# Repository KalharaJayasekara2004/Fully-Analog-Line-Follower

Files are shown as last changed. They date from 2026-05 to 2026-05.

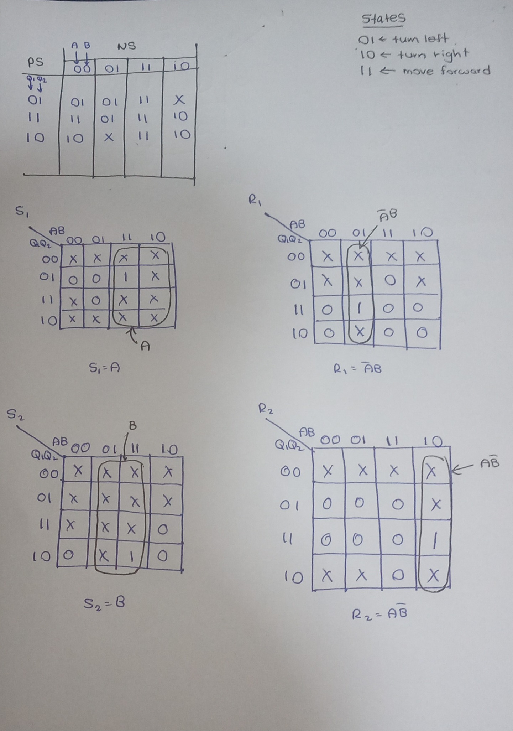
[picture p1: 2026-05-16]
Fully Analog Line Follower/Images/Logic.jpeg

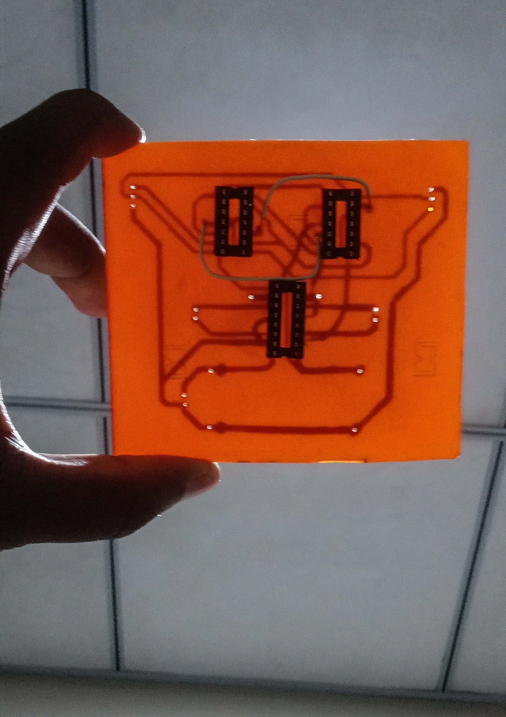
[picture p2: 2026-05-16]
Fully Analog Line Follower/Images/pcb.jpg

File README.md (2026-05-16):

# Fully Analog Line Following Robot

## 📌 Overview

This project presents the design and implementation of a fully analog line following robot developed for the EE2030 module at the University of Peradeniya.

The robot operates entirely without microcontrollers and is based on analog circuitry, logic gates, and flip-flop based control logic.

---

## ⚙️ Features

- Fully analog implementation
- No microcontroller usage
- SR flip-flop based control logic
- NAND gate logic optimization
- PCB-based hardware design
- Dash-line handling capability

---

## 🔧 Components Used

- KY-033 sensors
- L293D motor driver
- SR flip-flops
- NAND gates
- N20 DC motors
- Li-ion batteries

---

## 🖼️ Project Images

### Final Robot
Final Robot

---

## 🎥 Demonstration Video

[Click here to watch the final demonstration](https://drive.google.com/file/d/1bMnqlzevseig7BFVXOJsCPHhtffpjha0/view?usp=sharing)

---

## 📄 Documentation

The complete project report is available in the `report` folder.

---

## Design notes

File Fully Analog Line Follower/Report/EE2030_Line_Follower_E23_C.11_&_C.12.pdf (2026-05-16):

1

EE2030

# SEMESTER 3 - Group Project

## Group Members

E/23/135
E/23/138
E/23/145
E/23/150
E/23/151
E/23/158

# Week 01

## Week 1 – Initial Study and Logic Design

In Week 1, we first analyzed the basic operating logic of a line-following robot using two sensors. Based on the possible sensor output combinations, we constructed K-maps to simplify the control logic and determine the required motor control signals. This helped us to clearly understand how the robot should respond to different line positions. After gaining a rough understanding of the system behavior using two sensors, we extended the same approach to a three-sensor configuration in order to improve line detection accuracy and control reliability. The corresponding K-maps and logic diagrams were drawn and are included below.

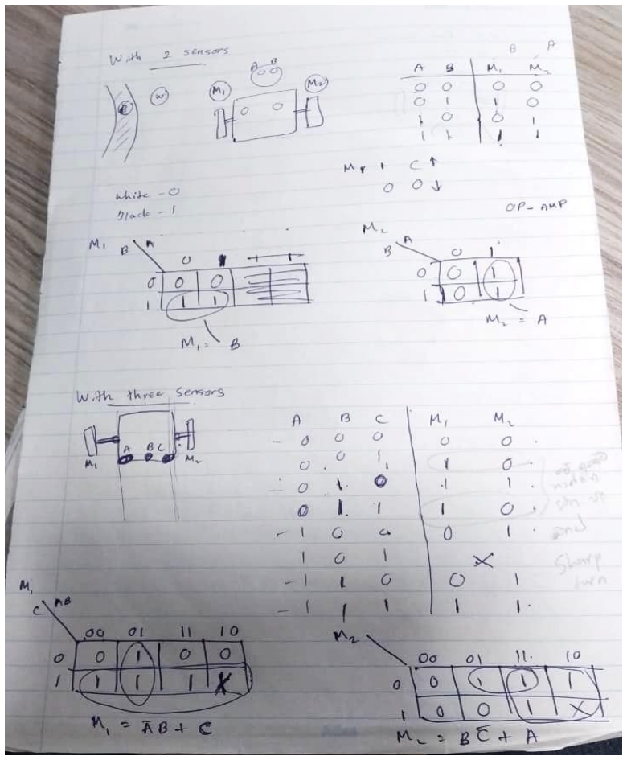
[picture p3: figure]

Figure 1: Karnaugh map representation for sensor-based motor control logic

# Week 02

## Week 2 – Sensor Signal Conditioning and Testing

In Week 2, we discussed methods to convert the analog output of the line sensors into digital signals suitable for control logic implementation. For this purpose, we decided to use operational amplifiers with adjustable potentiometers as comparators to set appropriate threshold levels. A rough circuit diagram was designed for the TCRT5000 sensor interfaced with an op-amp, and different sensor array configurations were evaluated to improve line detection accuracy. Through this analysis, we identified that a circular or V-shaped sensor array provides better line tracking performance compared to a straight-line configuration. Following the discussion session, the designed circuit was physically implemented and tested, using LED indicators to verify high and low output states of the comparator. The related circuit diagrams, implemented hardware, and sensor array configurations are shown below.

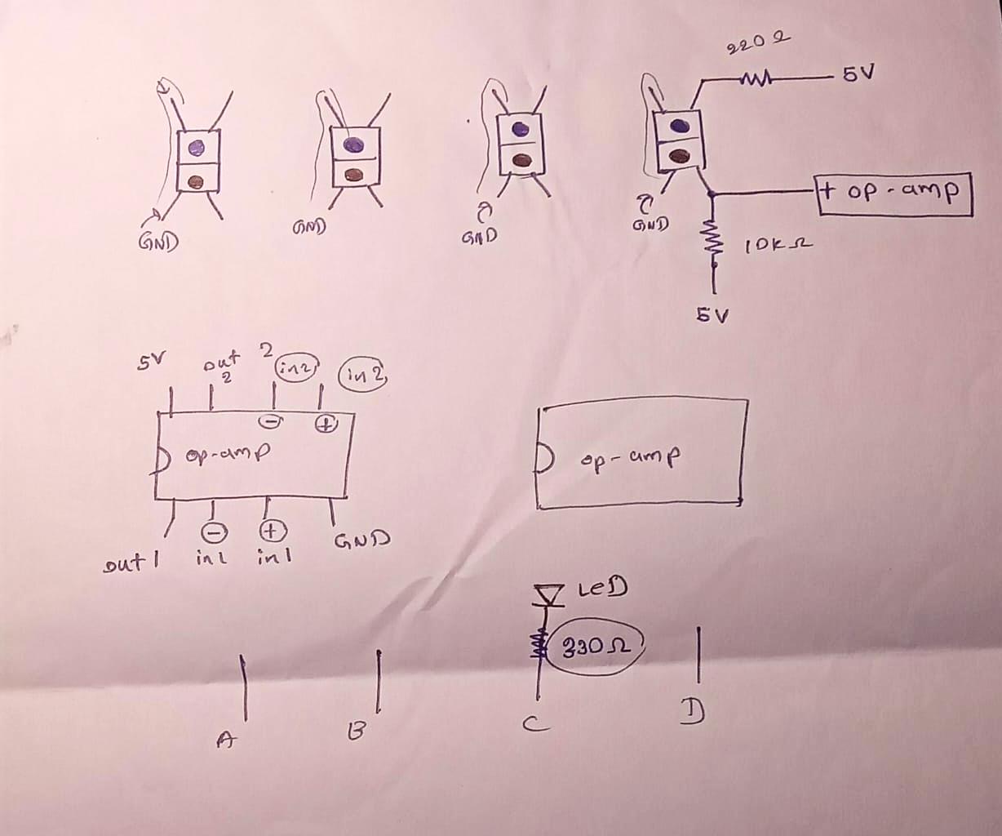
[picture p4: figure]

Figure 2.1: Rough circuit diagram of TCRT5000 sensor with op-amp comparator(LM358)

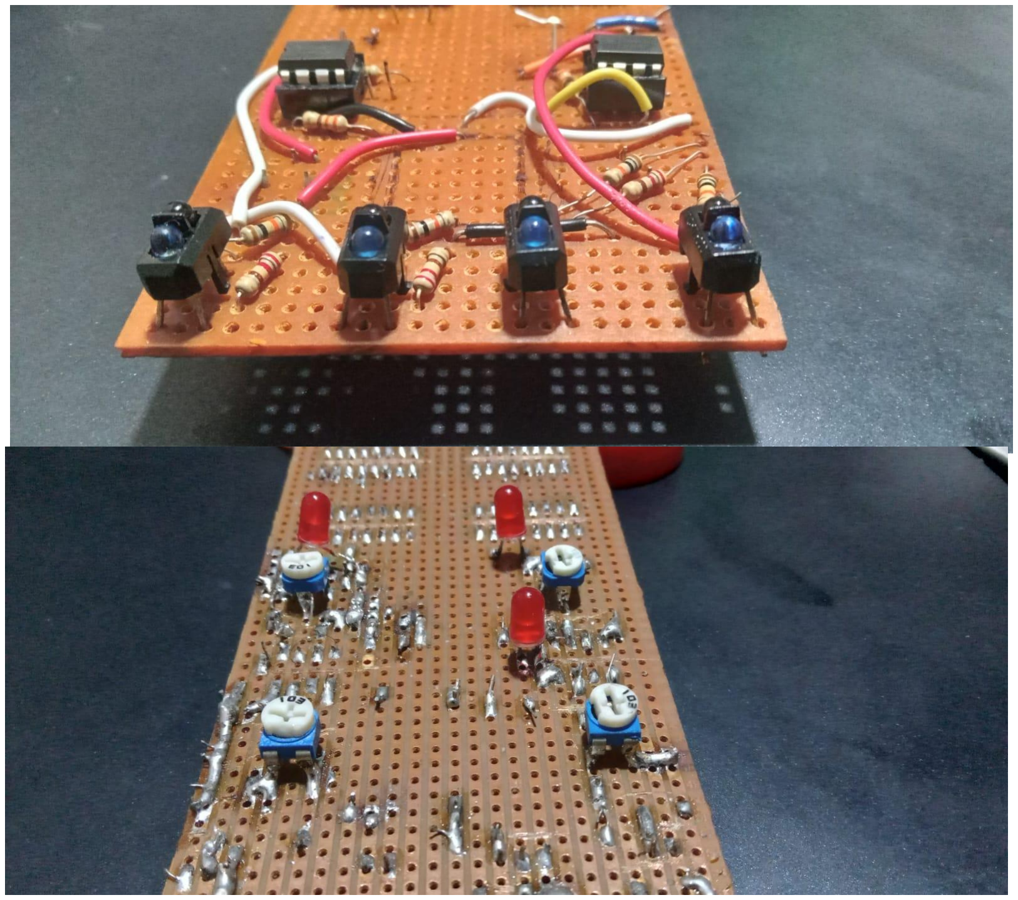
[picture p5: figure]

Figure 2.2: Physically implemented sensor and comparator circuit

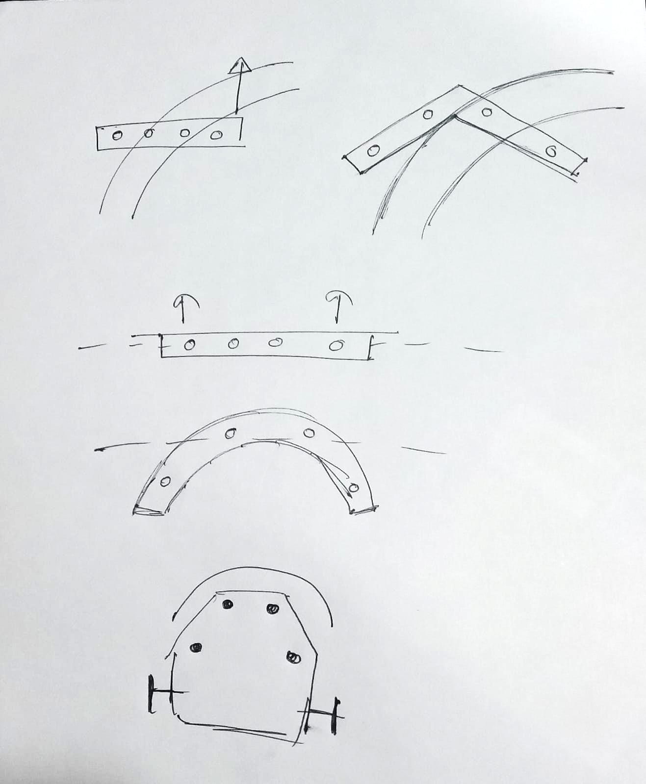
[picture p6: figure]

Figure 2.3: Comparison of different sensor array configurations

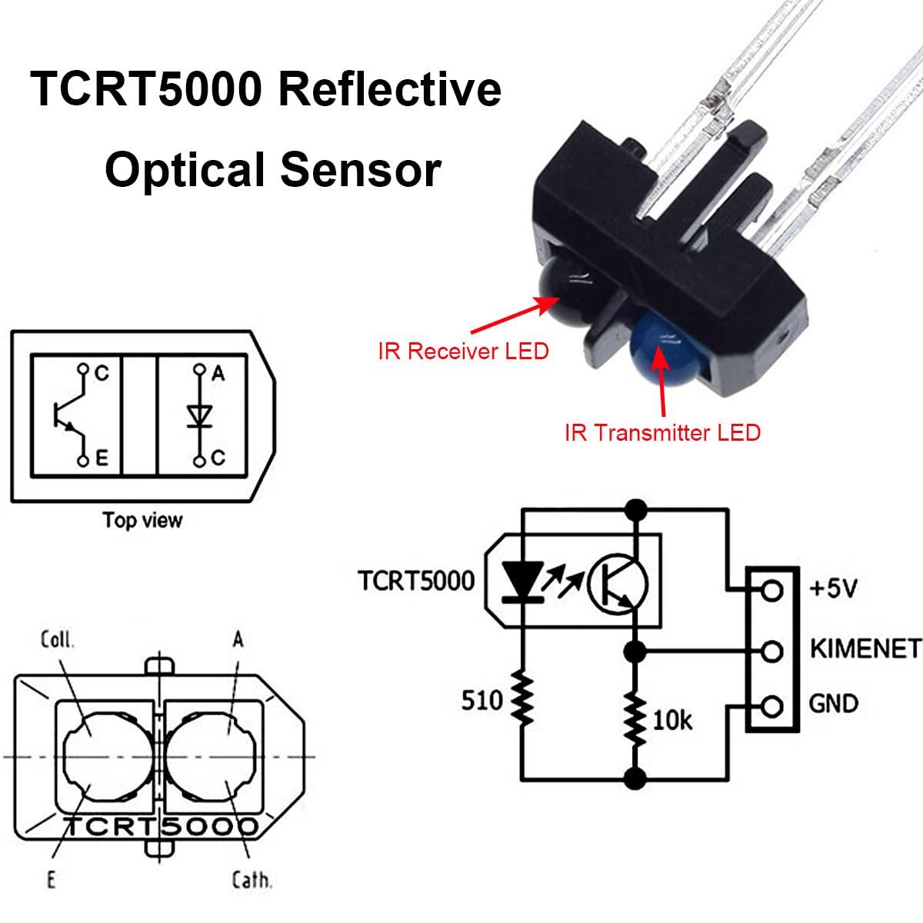
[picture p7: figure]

Figure 2.4: Pin configuration of the TCRT5000 reflective IR sensor (source: click here) (https://m.media-amazon.com/images/I/61pMG43RgvL.jpg)

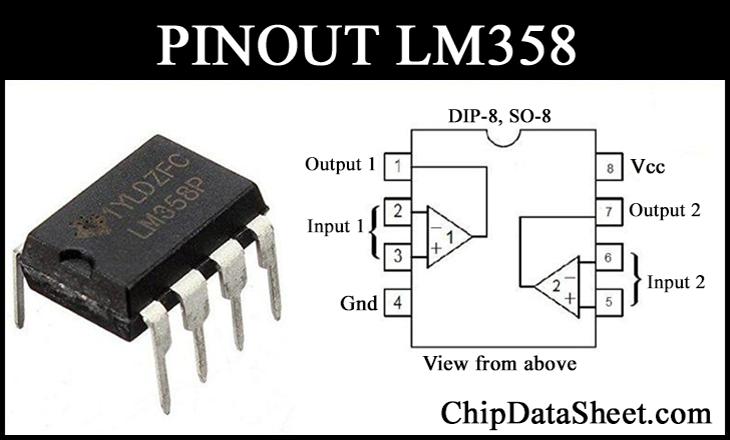
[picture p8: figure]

Figure 2.5: Pin configuration of the LM358 IC (source:click here) (https://chipdatasheet.com/wp-content/uploads/2022/09/Pin-LM358-DIP8-SO8-768x468-1.png)

# Week 03

## Week 3 – Multi-Sensor Logic Design and Speed Control

In Week 3, we improved the line follower design by extending the system from three sensors to four sensors. Based on the different line curvature conditions, Karnaugh maps were constructed to derive the control logic, and the corresponding IN1, IN2, IN3, and IN4 inputs of the motor driver were determined. The control strategy was designed such that, for slight turns, one wheel is driven while the other remains stopped, whereas for sharp turns, the wheels are driven in opposite directions to achieve faster reorientation.

During the discussion session of the same week, we explored methods to apply different PWM signals to the motor driver in order to control motor speed. As a fully analog solution, the NE555 timer IC was selected as a PWM generator. In addition, we discussed how the four-sensor logic could be extended to a six-sensor configuration. It was observed that by combining the outermost sensors on both sides using OR gates, the six-sensor system can be effectively reduced to an equivalent four-sensor input, allowing the previously designed logic to be reused. The derived logic diagrams, sensor-reduction method diagrams are included below.

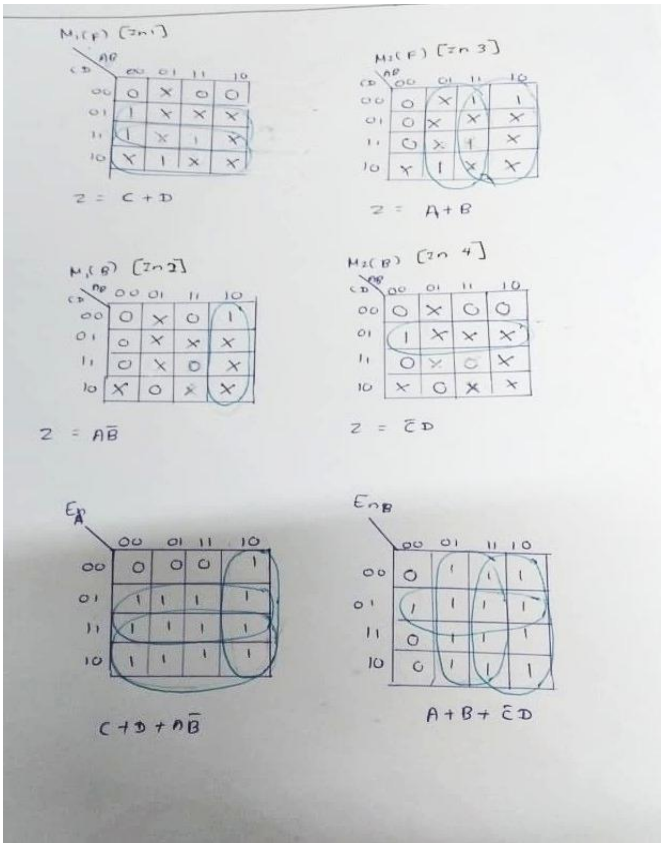
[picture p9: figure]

Figure 3.1: Four-sensor logic design and Karnaugh map simplification

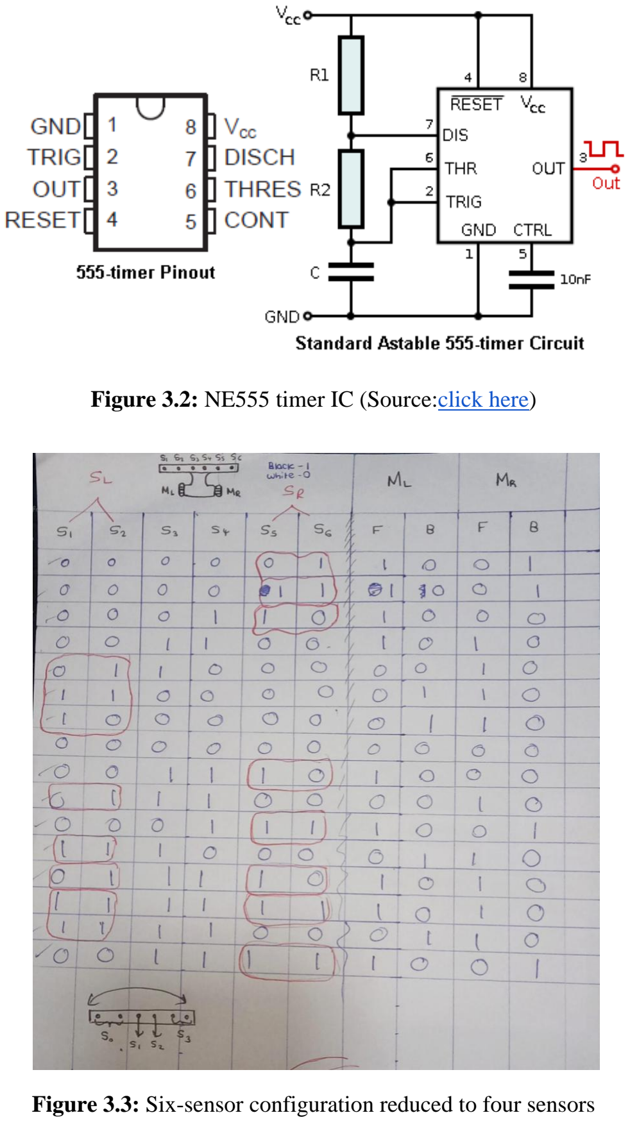
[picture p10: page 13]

Figure 3.2: NE555 timer IC (Source:click here) (https://cdn.sparkfun.com/assets/learn_tutorials/8/8/2/555-pinout.png)

Figure 3.3: Six-sensor configuration reduced to four sensors

# Week 04

## Week 4 (02.01 - 02.08) – Implementation of D-Latch Based Memory Logic

In Week 05, we focused on improving the two-sensor line follower by incorporating memory elements using D-latches. The objective was to derive suitable Boolean expressions for two D-latches in order to enhance the robot’s response when it deviates from a curve.

Logic expressions were developed such that when the robot moves away from the line during a turning condition, the stored state in the D-latch enables the system to guide the robot back toward the line instead of stopping immediately. This approach improves stability and reduces unnecessary interruptions in motion.

The complete derivation of the D-latch logic expressions and corresponding circuit diagrams are included below.

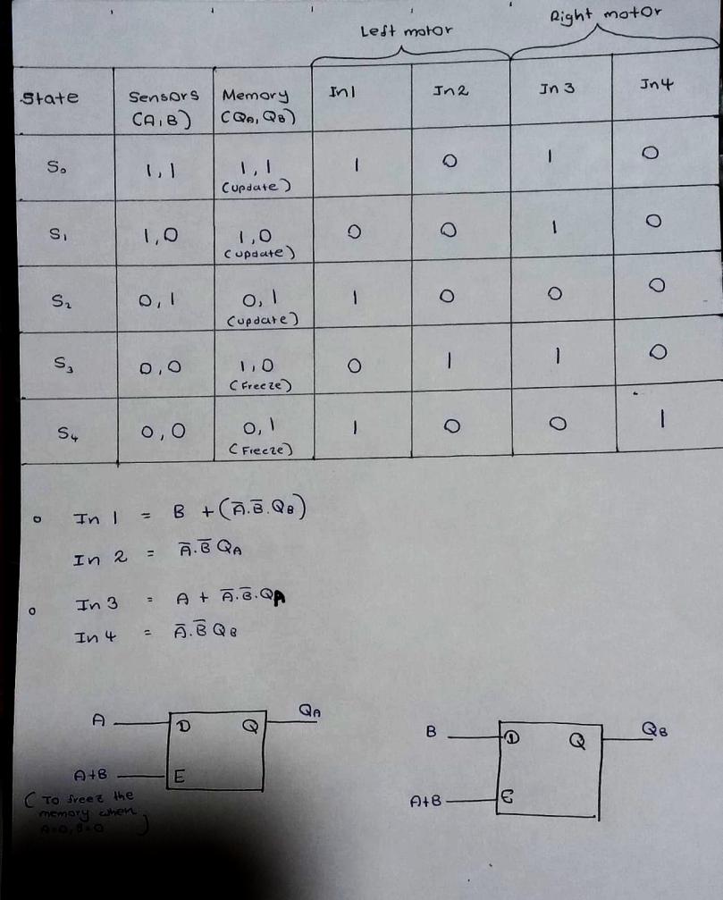
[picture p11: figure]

Figure 4.1: Derivation of Boolean expressions for D-latch based control logic

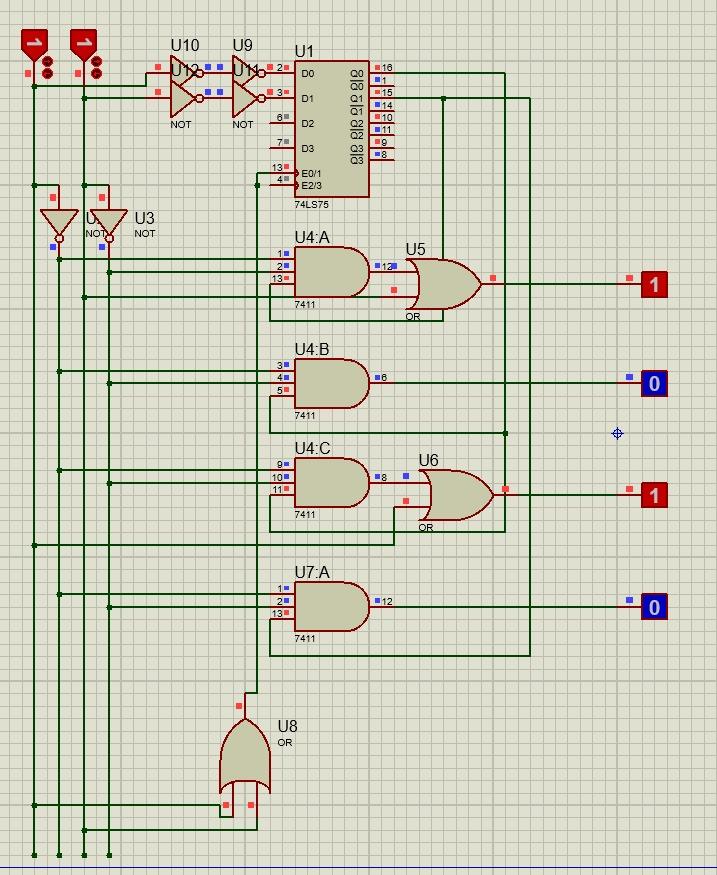
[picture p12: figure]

Figure 4.2: D-Latch Based Circuit in Proteus

# Week 05

## Week 5 (02.08 – 02.15) – Prototype Implementation and Testing

During this week, a functional test prototype of the line-following robot was constructed using two KY-033 line tracking sensors, an L293D motor driver IC, and two N20 200 RPM (6 V) DC motors. The system was powered by two 3.7 V, 1850 mAh Li-ion batteries connected in series, providing 7.4 V, and LM2596 DC buck converter was used to step down the voltage to 5 V for appropriate circuit operation.

The control logic implemented in this prototype was based on the Boolean expressions derived during the Week 1 discussion session for the two-sensor configuration. After assembling the hardware, the robot was tested on a black tape line track to evaluate its performance. The prototype successfully followed the line according to the designed logic. Images of the constructed robot and a video recording of the testing procedure are included below for reference.

Video 1: Two-Sensor Line Follower Testing Click here to view the testing video (https://drive.google.com/file/d/1RQrxIO05CoGl9LaXGkrLNTandFtSJKMJ/view?usp=drive_link)

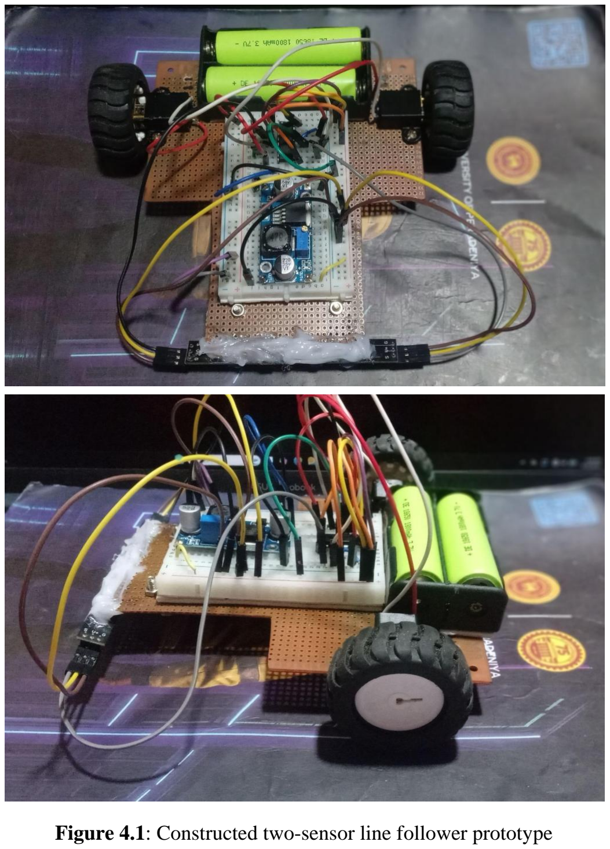
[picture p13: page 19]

Figure 4.1: Constructed two-sensor line follower prototype

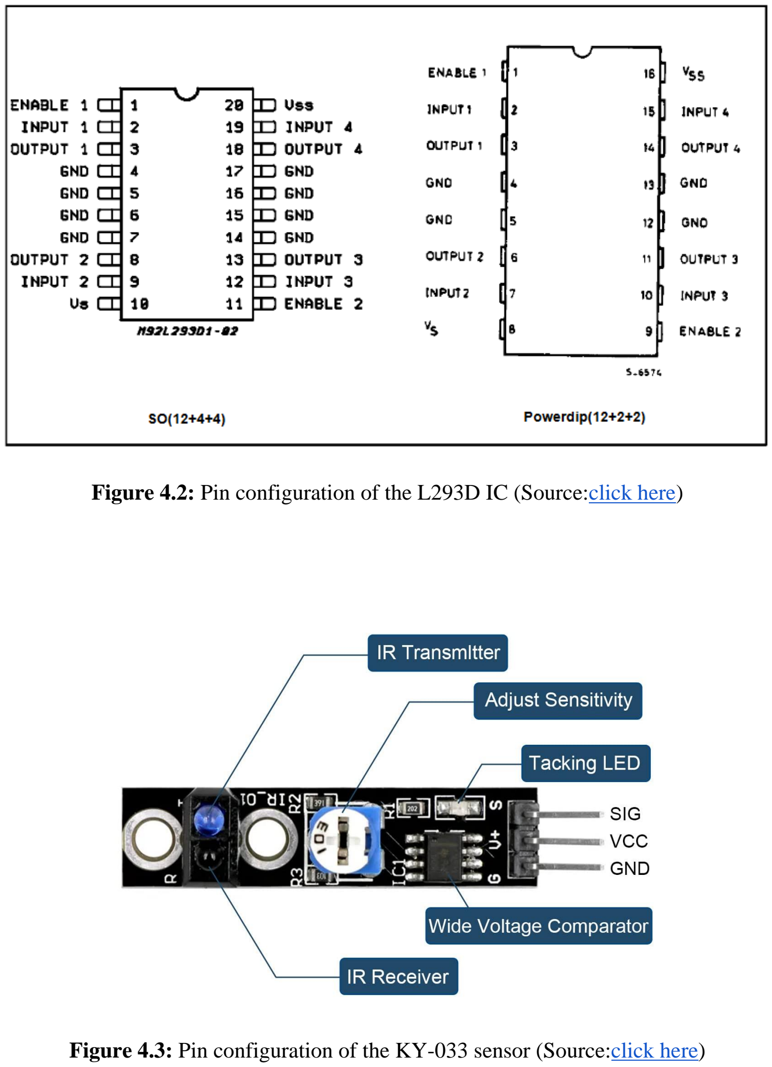
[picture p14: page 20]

Figure 4.2: Pin configuration of the L293D IC (Source:click here) (https://www.alldatasheet.com/datasheet-pdf/view/22432/STMICROELECTRONICS/L293D.html)

Figure 4.3: Pin configuration of the KY-033 sensor (Source:click here) (https://m.media-amazon.com/images/I/61zlxI2YXHL._SL1200_.jpg)

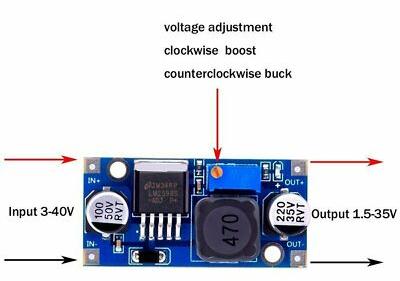
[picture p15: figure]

Figure 4.4: Pin configuration of the LM2596 DC buck converter (Source:click here) (https://i.ebayimg.com/images/g/r3oAAOSwAvVjGtWj/s-l400.jpg)

# Week 06

## Week 6 (02.15 – 02.22) – Testing and Identified Limitations

In Week 6, the two-sensor line follower prototype was tested on the final project track. The robot performance exceeded our initial expectations, demonstrating stable and accurate line tracking under standard conditions.

However, during testing on the dashed-line sections of the track, a limitation was observed. Although we initially expected the robot to continue moving forward due to its operating speed when encountering short white gaps, it instead stopped whenever both sensors detected a white region. This behavior occurred because the existing logic interprets the white space as a loss of line, resulting in a stop condition.

To address this issue, we proposed modifying the control logic such that when both sensors detect white simultaneously for a short duration, the robot continues moving forward instead of stopping. This adjustment is expected to improve performance over dashed-line segments while maintaining stability in normal operation.

The testing process and observed behavior are demonstrated in the video provided below.

Video 2: Two-Sensor Line Follower Testing
Click here to view the testing video (https://drive.google.com/file/d/11rcb2jxFlQWycFH8yF17M4YXdiSHCvTV/view?usp=drive_link)

# Week 07

## Week 07 (02.22-02.28) – Dash-Line Logic Improvement and NAND-Based Optimization

In Week 07, we addressed the stopping issue observed when the robot encountered dashed-line segments. Previously, when both sensors detected a white surface (logic 0,0), the robot was designed to stop. To overcome this limitation, a new control logic was defined such that when both sensors detect white simultaneously, the robot continues moving forward instead of stopping.

The initial implementation of this modified logic required two OR gates and two NOT gates, which resulted in the need for two additional ICs. However, further simplification was performed by redesigning the logic using only NAND gates. Through NAND-only implementation, the same functionality was achieved using four NAND gates, requiring only one additional IC. This significantly reduced hardware complexity and improved circuit efficiency.

The updated logic derivation, NAND-based circuit implementation, and dash-line performance testing are presented below.

Video 3: Performance testing on dashed-line track after logic modification

Click here to watch the video (https://drive.google.com/file/d/1hXyRKGLtQTlIfI6CsDXNodcf5WFhqbHW/view?usp=drive_link)

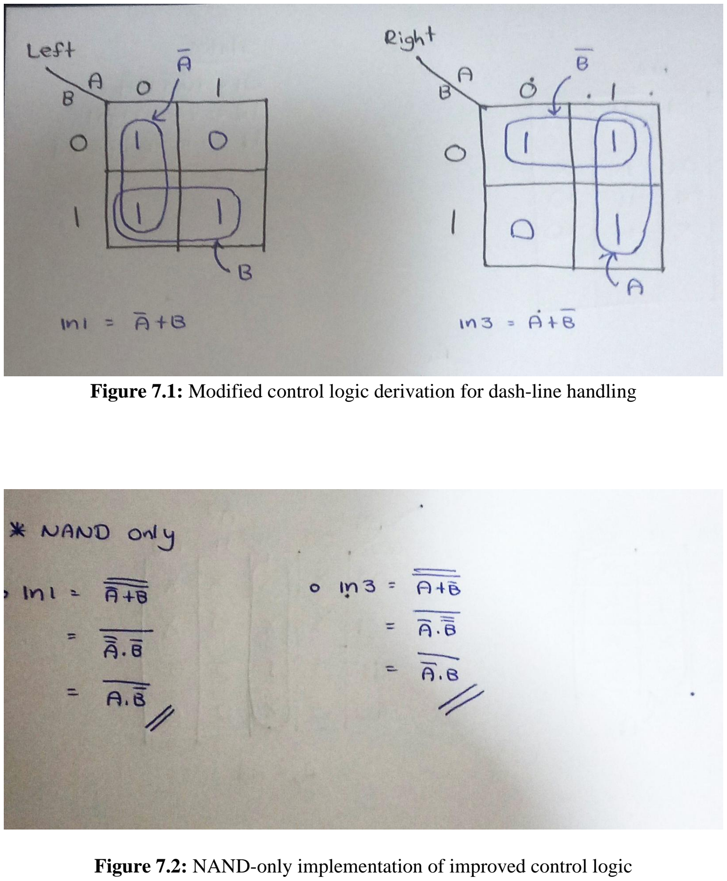
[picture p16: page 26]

Figure 7.1: Modified control logic derivation for dash-line handling

Figure 7.2: NAND-only implementation of improved control logic

# Week 08

## Week 08 (03.08 - 03.15) – Final Track Testing and Analysis of Dash-Line Deviation

In Week 08, the robot was tested again on the final track to evaluate the effectiveness of the previously implemented improvements. During this test, it was observed that the robot deviates from the track when encountering dashed-line segments, particularly while negotiating curves.

Upon analysis, we identified that during a turning condition, both sensors briefly pass over the first white gap in the dashed line. This causes the control logic to misinterpret the situation, resulting in the robot moving away from the intended path.

As a preliminary solution, we proposed reducing the length of the robot chassis, which would allow the sensors to follow the curve more closely. This adjustment is expected to minimize simultaneous white detection during turns and improve performance over dashed-line sections.

The observed behavior, along with a conceptual explanation of the issue and the proposed solution, are illustrated in the video and sketch provided below.

Video 4: Robot deviation observed on dashed-line curve in final track

click here to watch the video (https://drive.google.com/file/d/1iiciaqwBfbHksBd2YMei0SfmxA4roiQH/view?usp=drive_link)

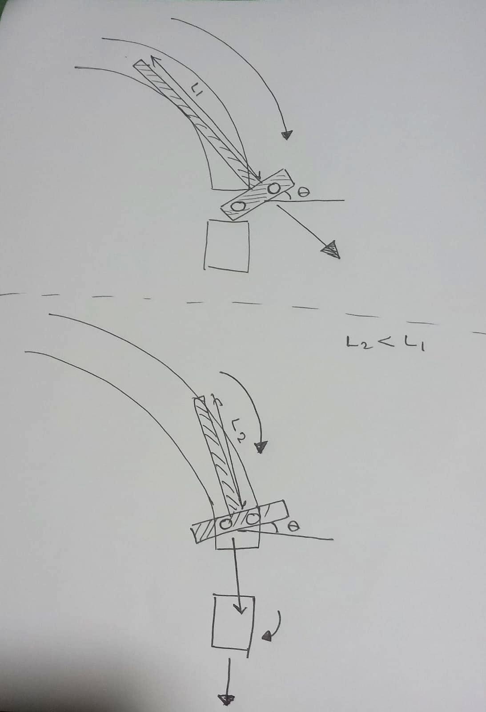
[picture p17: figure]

Figure 8.1: Sketch illustrating sensor behavior during dashed-line curve deviation

# Week 09

## Week 09 (03.15 - 03.22) – Mechanical Optimization and Final Validation

In Week 09, the physical design of the line follower robot was refined by reducing the overall chassis length to improve maneuverability, especially on curved and dashed-line sections. In addition, the circuit implementation was transitioned from a breadboard with jumper wires to a soldered vero board, resulting in a more stable and reliable hardware configuration. This change minimized loose connections and improved signal consistency.

Although integrating all components into the smaller chassis was challenging, the compact design contributed to improved tracking performance. After completing these modifications, the robot was tested on the final track, where it demonstrated stable and accurate operation. To achieve optimal performance, fine adjustments were made to the potentiometer settings of both sensors to ensure correct threshold detection.

The final robot design and its performance on the track are shown in the images and video provided below.

Video 5: Final performance of the robot on the project track

click here to watch the video (https://drive.google.com/file/d/1ZlXcmXYIYVBtRVts5-Ni0v4t3DnI98Q9/view?usp=drive_link)

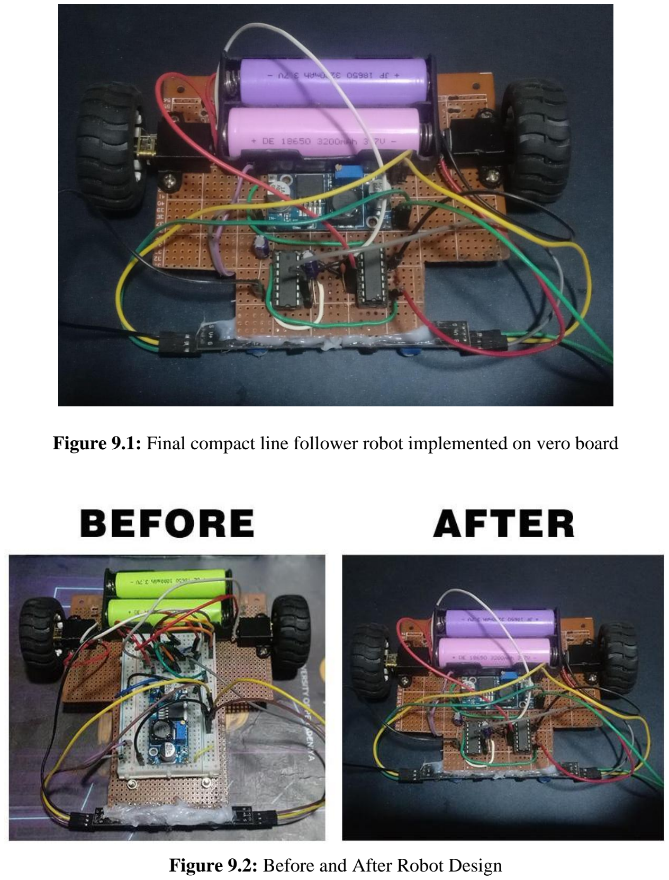
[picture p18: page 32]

Figure 9.1: Final compact line follower robot implemented on vero board

Figure 9.2: Before and After Robot Design

# Week 10

## Week 10 (04.19 - 04.25) – Flip-Flop Based Design and PCB-Oriented Development

In Week 10, we initiated the design of a new line follower system incorporating flip-flop based control logic and a printed circuit board (PCB) to achieve a cleaner and more reliable hardware implementation. Unlike the previous prototype, which did not utilize flip-flops and was not PCB-based, this design aims to improve structural organization and signal stability.

As a first step, we derived the logical expressions for the control system using two SR flip-flops to introduce memory into the line-following behavior. This approach allows the robot to retain state information and respond more effectively to changes in the track.

The derived logic was then simulated in Proteus Design Suite to verify correct operation before proceeding to hardware implementation. The logic derivations and simulation results are presented below.

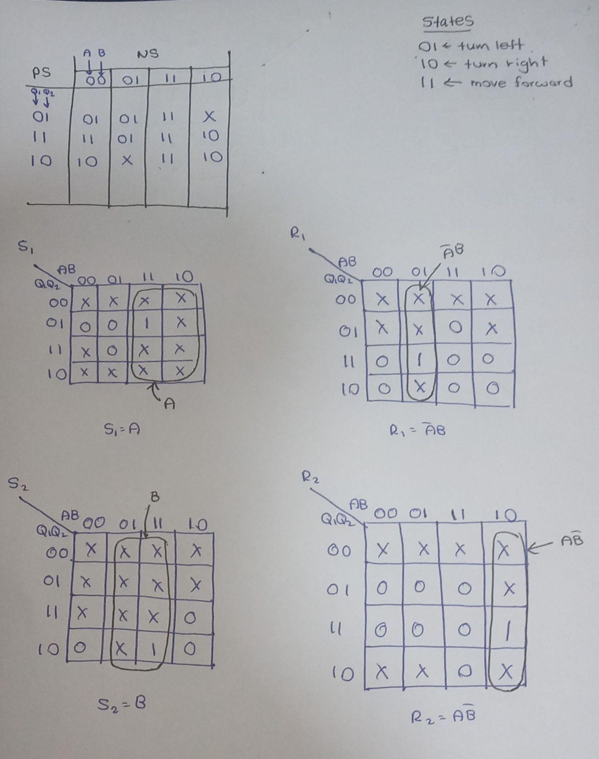
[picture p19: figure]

Figure 10.1: Derivation of control logic using SR flip-flops

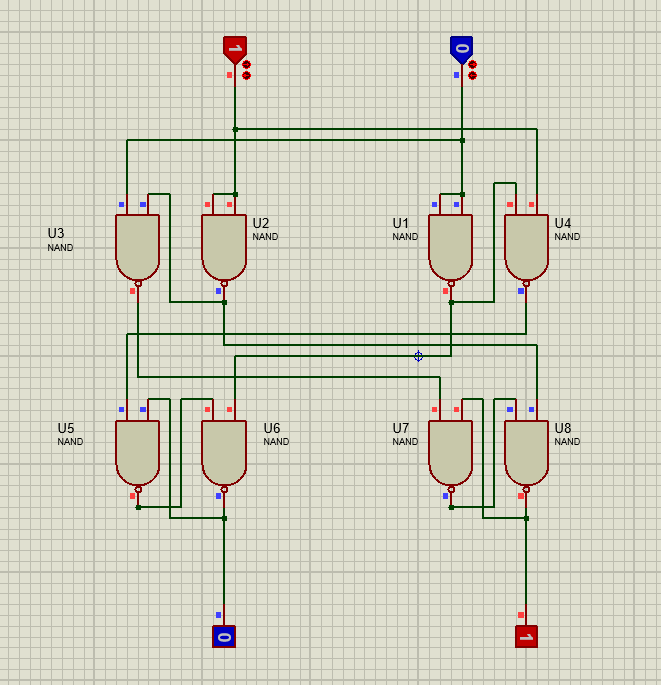
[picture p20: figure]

Figure 10.2: Proteus simulation of flip-flop based line follower circuit

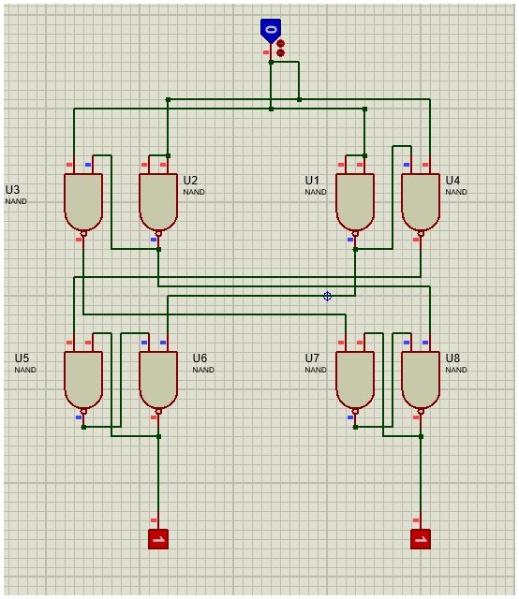
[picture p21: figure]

Figure 10.3: Proteus simulation for dash lines

# Week 11

## Week 11 (04.25 - 05.01) – PCB Fabrication, Assembly, and System Debugging

In Week 11, we designed a single-layer PCB for the line follower using KiCad and proceeded with in-house fabrication. The PCB layout was printed on photo paper and transferred onto a copper board using the toner transfer (ironing) method. After transfer, any missing traces were corrected using a permanent marker, and the board was then etched in a Ferric Chloride solution for approximately 30 minutes with continuous agitation.

Once etching was complete, the remaining toner was removed using nail polish remover, and holes were drilled for component placement. The components were then soldered onto the PCB, and necessary air wires were added due to the single-layer design constraints. Following this, external components including sensors, motors, wheels, caster wheel, switch, and batteries were integrated to complete the robot assembly.

During initial power-up, the robot did not function as expected. A systematic debugging process was carried out using a multimeter continuity test, which revealed grounding issues in the circuit. After correcting and re-soldering the faulty connections, both sensors and motors operated correctly.

Subsequent testing on a track showed unstable behavior. This was resolved by increasing the distance between the sensors and the ground surface, which significantly improved detection accuracy. Although a minor propagation delay was observed in dashed-line sections due to the use of SR flip-flops, it did not critically affect overall performance. An alternative improvement could be the use of JK flip-flops to reduce such effects; however, this was not implemented due to the finalized PCB design.

Overall, the robot demonstrated satisfactory performance on the test track and final track after these adjustments. The design process, PCB fabrication stages, assembly, and testing results are illustrated below.

Video 6: Testing of PCB-based robot on track
click here to watch the video (https://drive.google.com/file/d/1jxqBJltSNDDSN6D_FDN8Y4sTolbwB6vP/view?usp=drive_link)

Video 7: Final performance of the robot on the project track click here to watch the video (https://drive.google.com/file/d/1bMnqlzevseig7BFVXOJsCPHhtffpjha0/view?usp=sharing)

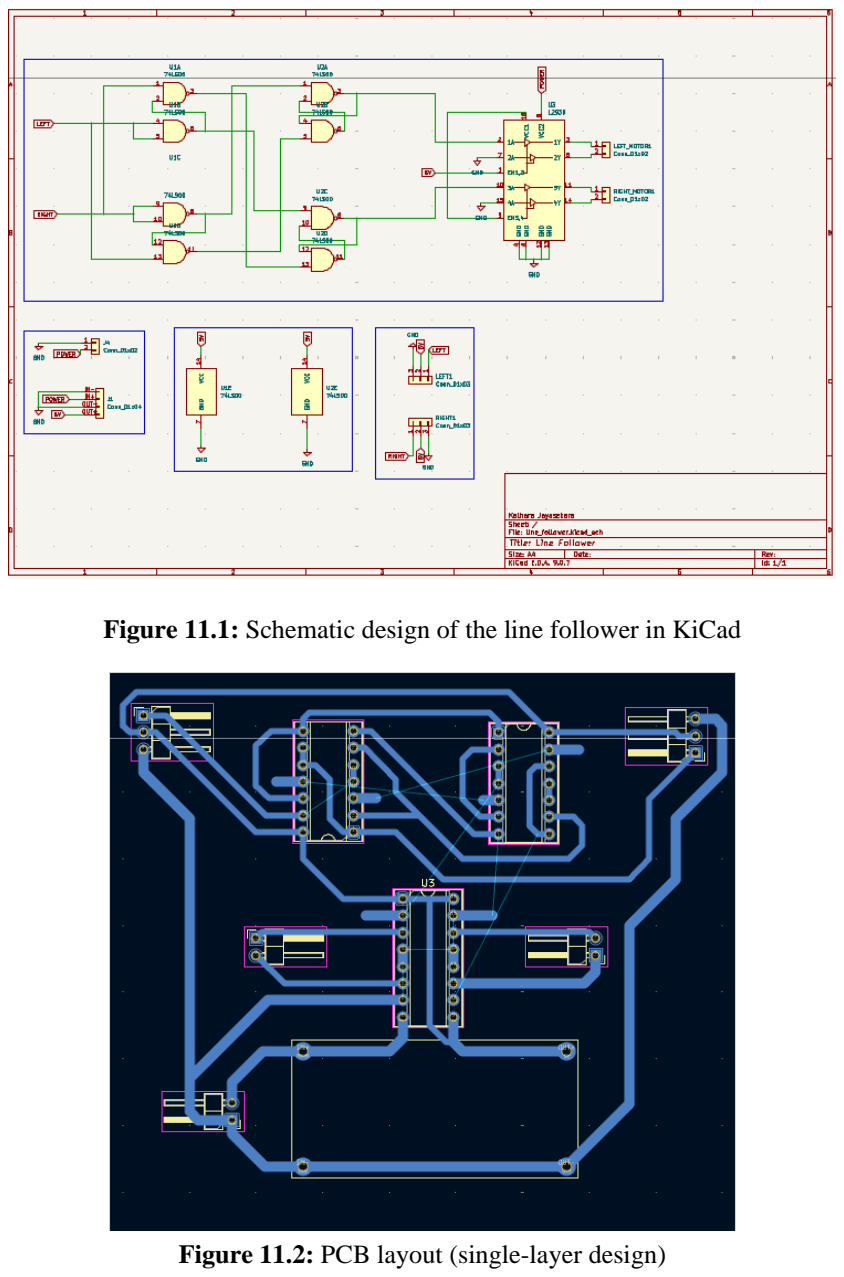
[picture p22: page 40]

Figure 11.1: Schematic design of the line follower in KiCad

Figure 11.2: PCB layout (single-layer design)

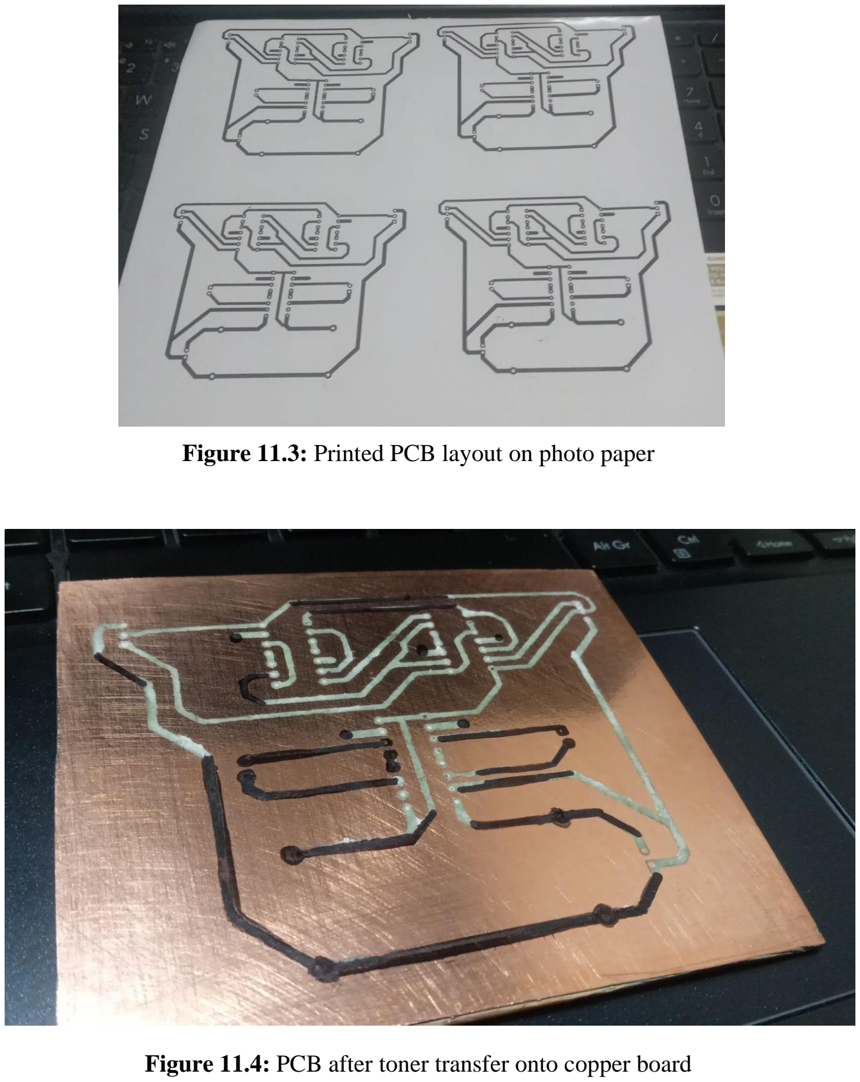
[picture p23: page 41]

Figure 11.3: Printed PCB layout on photo paper

Figure 11.4: PCB after toner transfer onto copper board

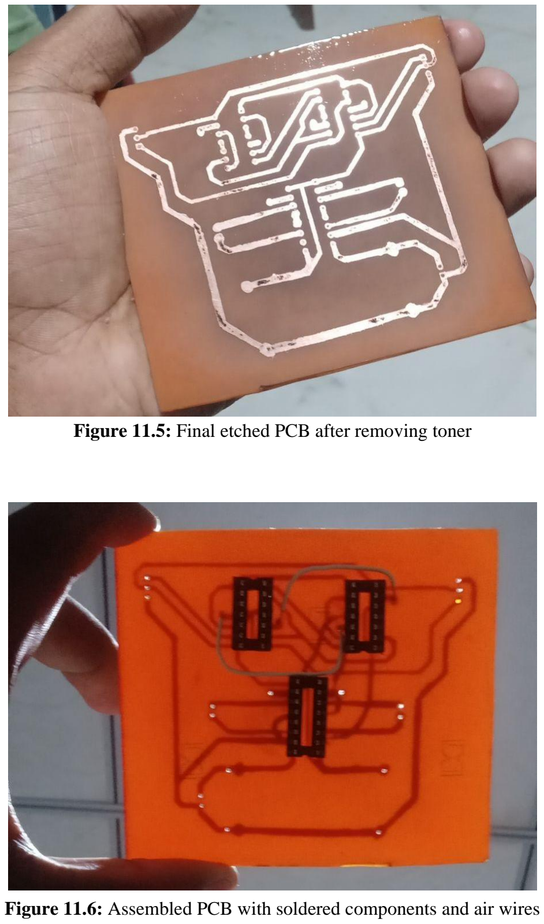
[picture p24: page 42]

Figure 11.5: Final etched PCB after removing toner

Figure 11.6: Assembled PCB with soldered components and air wires

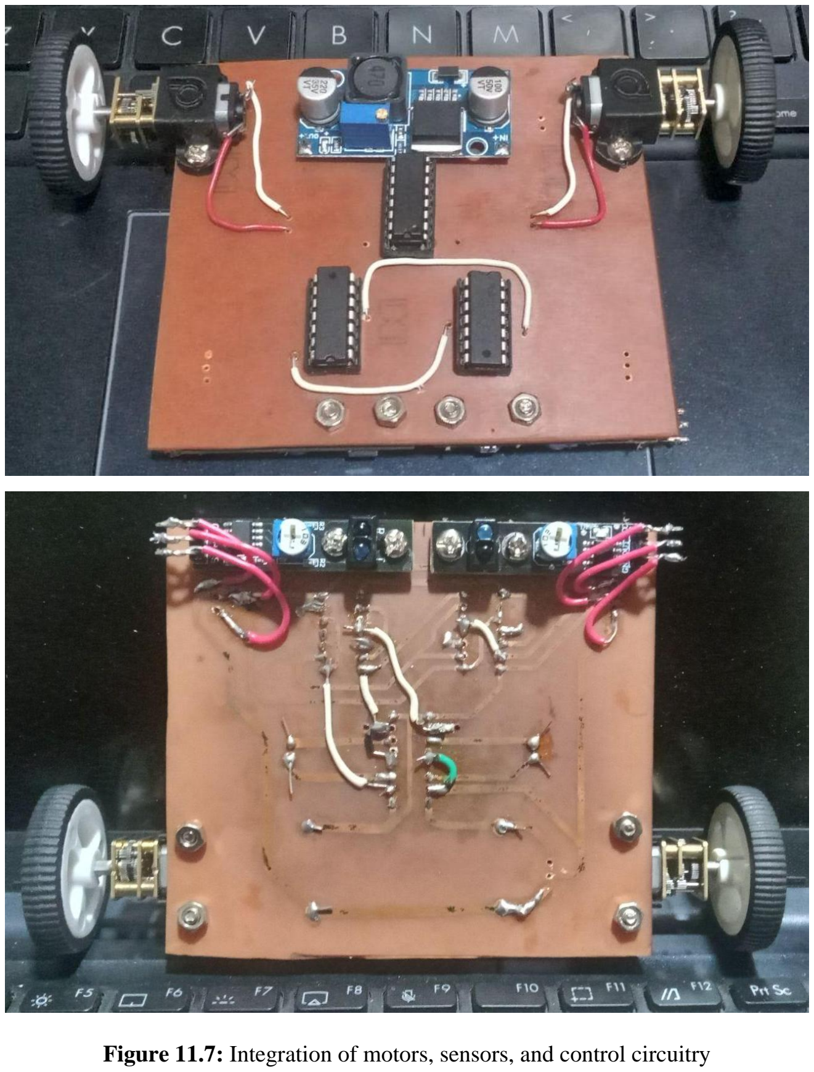
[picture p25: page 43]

Figure 11.7: Integration of motors, sensors, and control circuitry

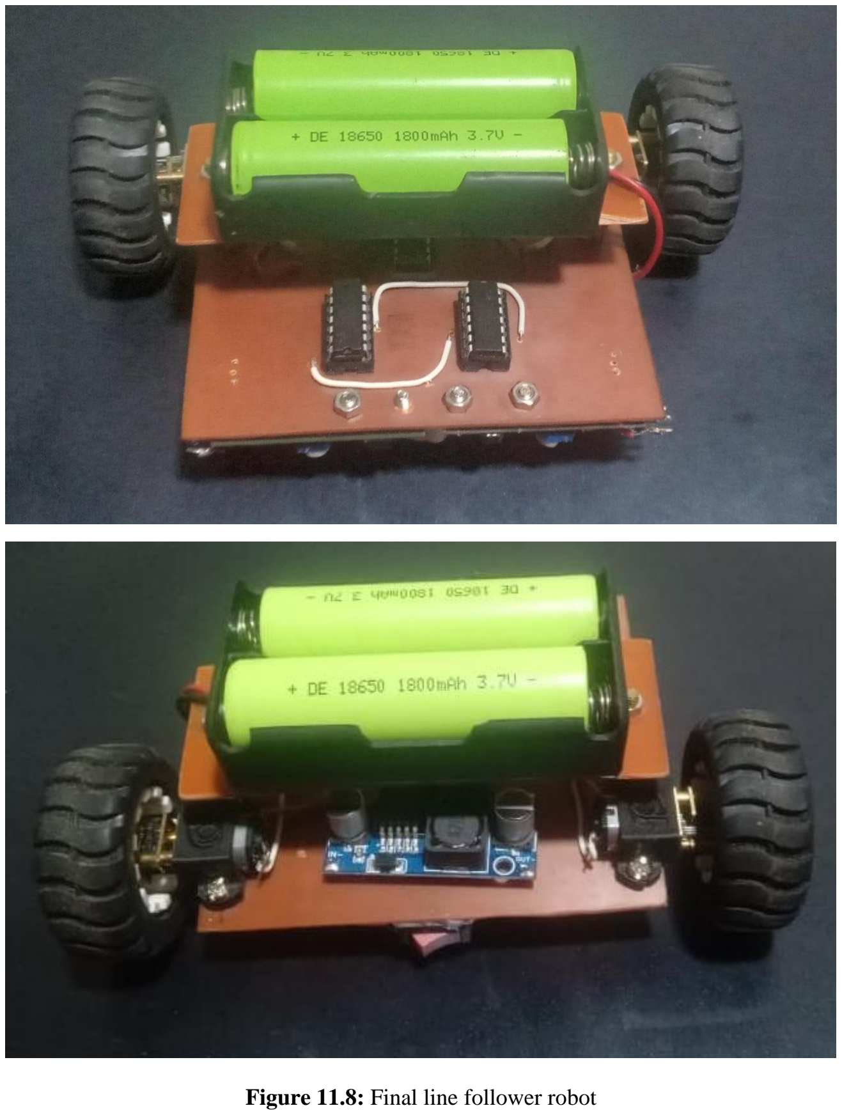
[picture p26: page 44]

Figure 11.8: Final line follower robot

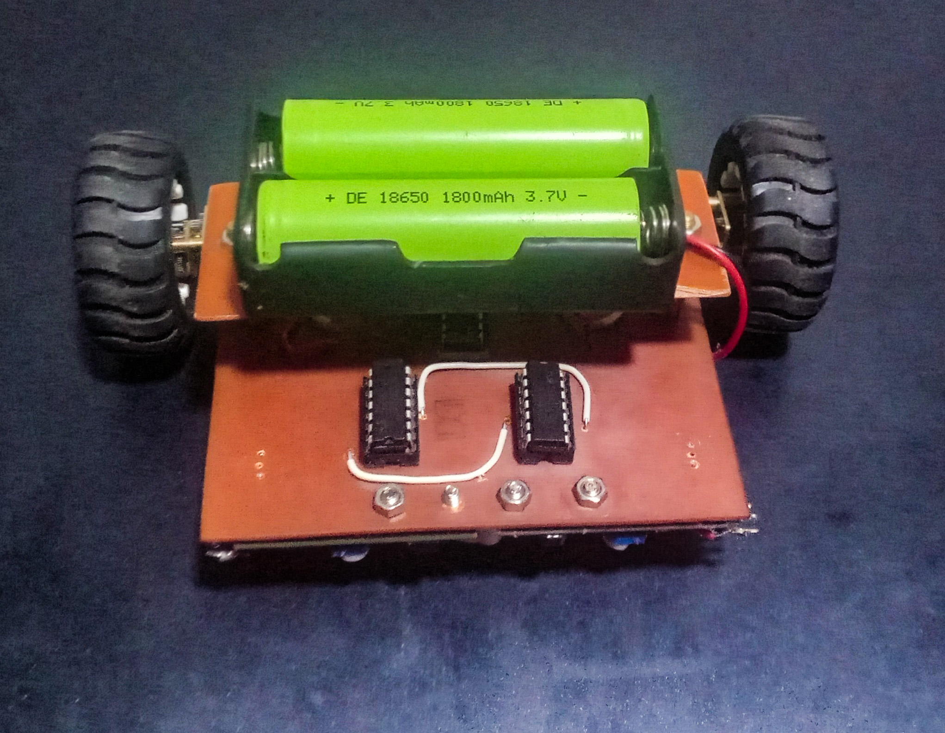
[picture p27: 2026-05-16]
Fully Analog Line Follower/Images/Final_Robot.jpg

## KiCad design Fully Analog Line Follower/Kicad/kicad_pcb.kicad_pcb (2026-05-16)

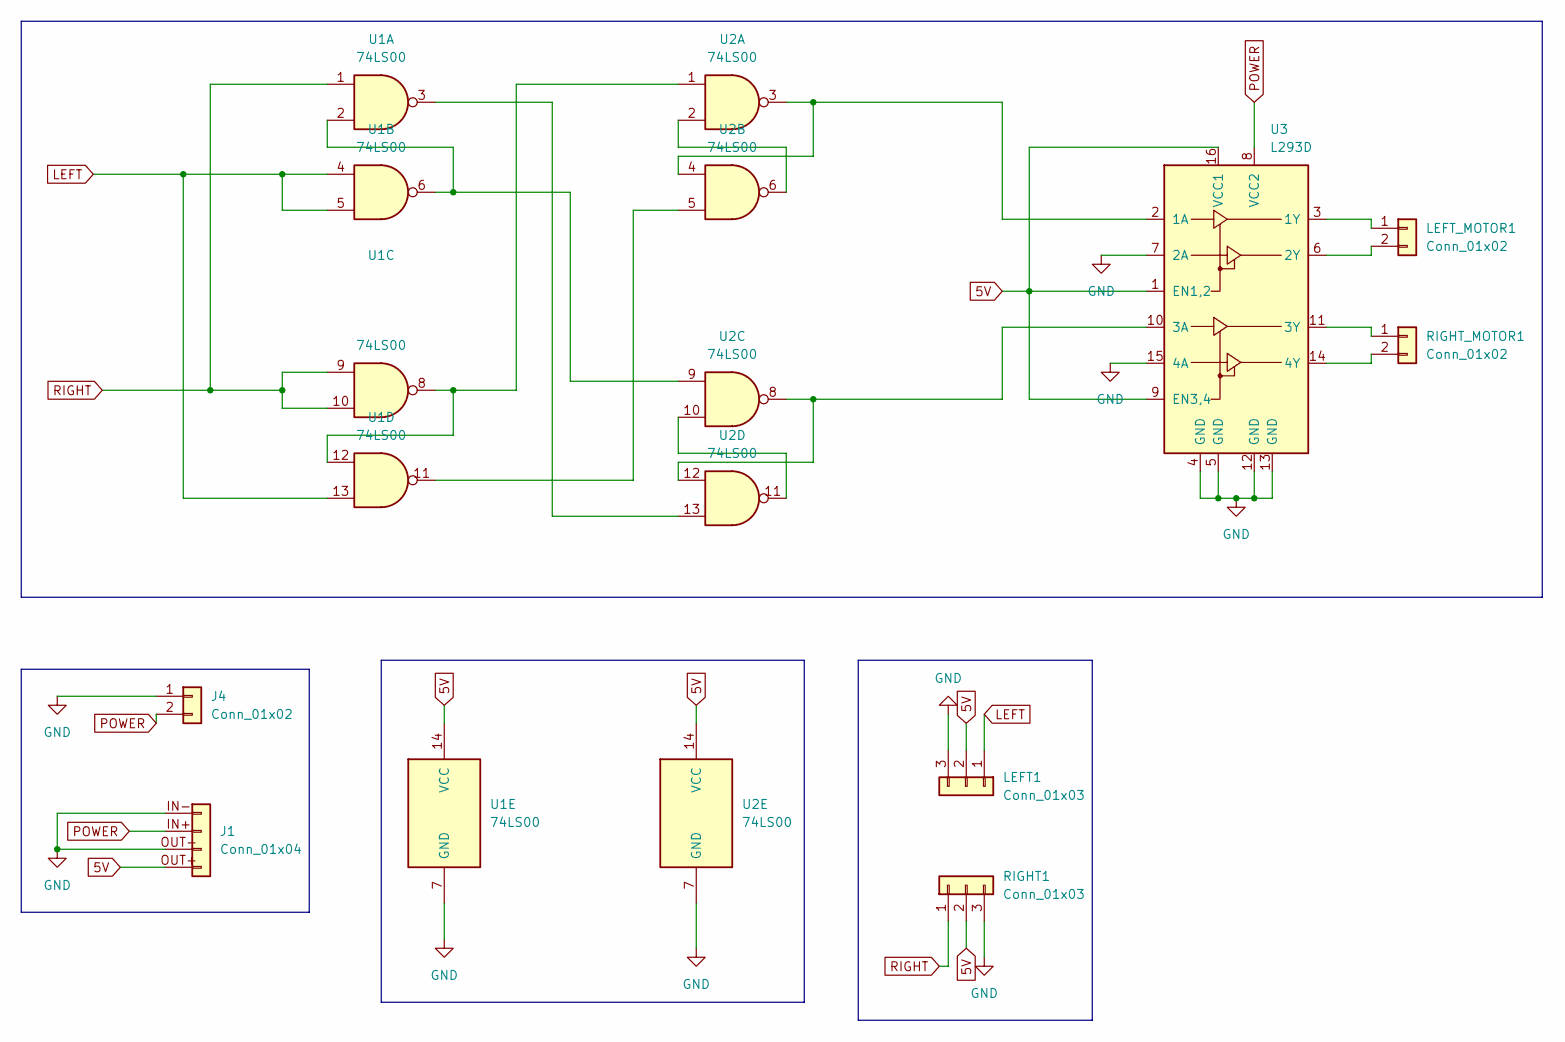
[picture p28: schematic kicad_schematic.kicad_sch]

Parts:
J1: Conn_01x04; LM2596
J4: Conn_01x02; PinHeader_1x02_P2.54mm_Horizontal
LEFT1: Conn_01x03; PinHeader_1x03_P2.54mm_Horizontal
LEFT_MOTOR1: Conn_01x02; PinHeader_1x02_P2.54mm_Horizontal
RIGHT1: Conn_01x03; PinHeader_1x03_P2.54mm_Horizontal
RIGHT_MOTOR1: Conn_01x02; PinHeader_1x02_P2.54mm_Horizontal
U1, U2: 74LS00; DIP-14_W7.62mm_Socket
U3: L293D; DIP-16_W7.62mm_Socket

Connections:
5V: J1.OUT+ (Pin_4), LEFT1.2, RIGHT1.2, U1.14 (VCC), U2.14 (VCC), U3.1 (EN1,2), U3.9 (EN3,4), U3.16 (VCC1)
GND: J1.IN- (Pin_1), J1.OUT- (Pin_3), J4.1, LEFT1.3, RIGHT1.3, U1.7 (GND), U2.7 (GND), U3.4 (GND), U3.5 (GND), U3.7 (2A), U3.12 (GND), U3.13 (GND), U3.15 (4A)
LEFT: LEFT1.1, U1.4, U1.5, U1.13
unnamed: LEFT_MOTOR1.1, U3.3 (1Y)
unnamed: LEFT_MOTOR1.2, U3.6 (2Y)
unnamed: RIGHT_MOTOR1.1, U3.11 (3Y)
unnamed: RIGHT_MOTOR1.2, U3.14 (4Y)
unnamed: U1.2, U1.6, U2.9
unnamed: U1.3, U2.13
unnamed: U1.11, U2.5
unnamed: U1.8, U1.12, U2.1
unnamed: U2.2, U2.6
unnamed: U2.10, U2.11
unnamed: U2.3, U2.4, U3.2 (1A)
unnamed: U2.8, U2.12, U3.10 (3A)
POWER: J1.IN+ (Pin_2), J4.2, U3.8 (VCC2)
RIGHT: RIGHT1.1, U1.1, U1.9, U1.10

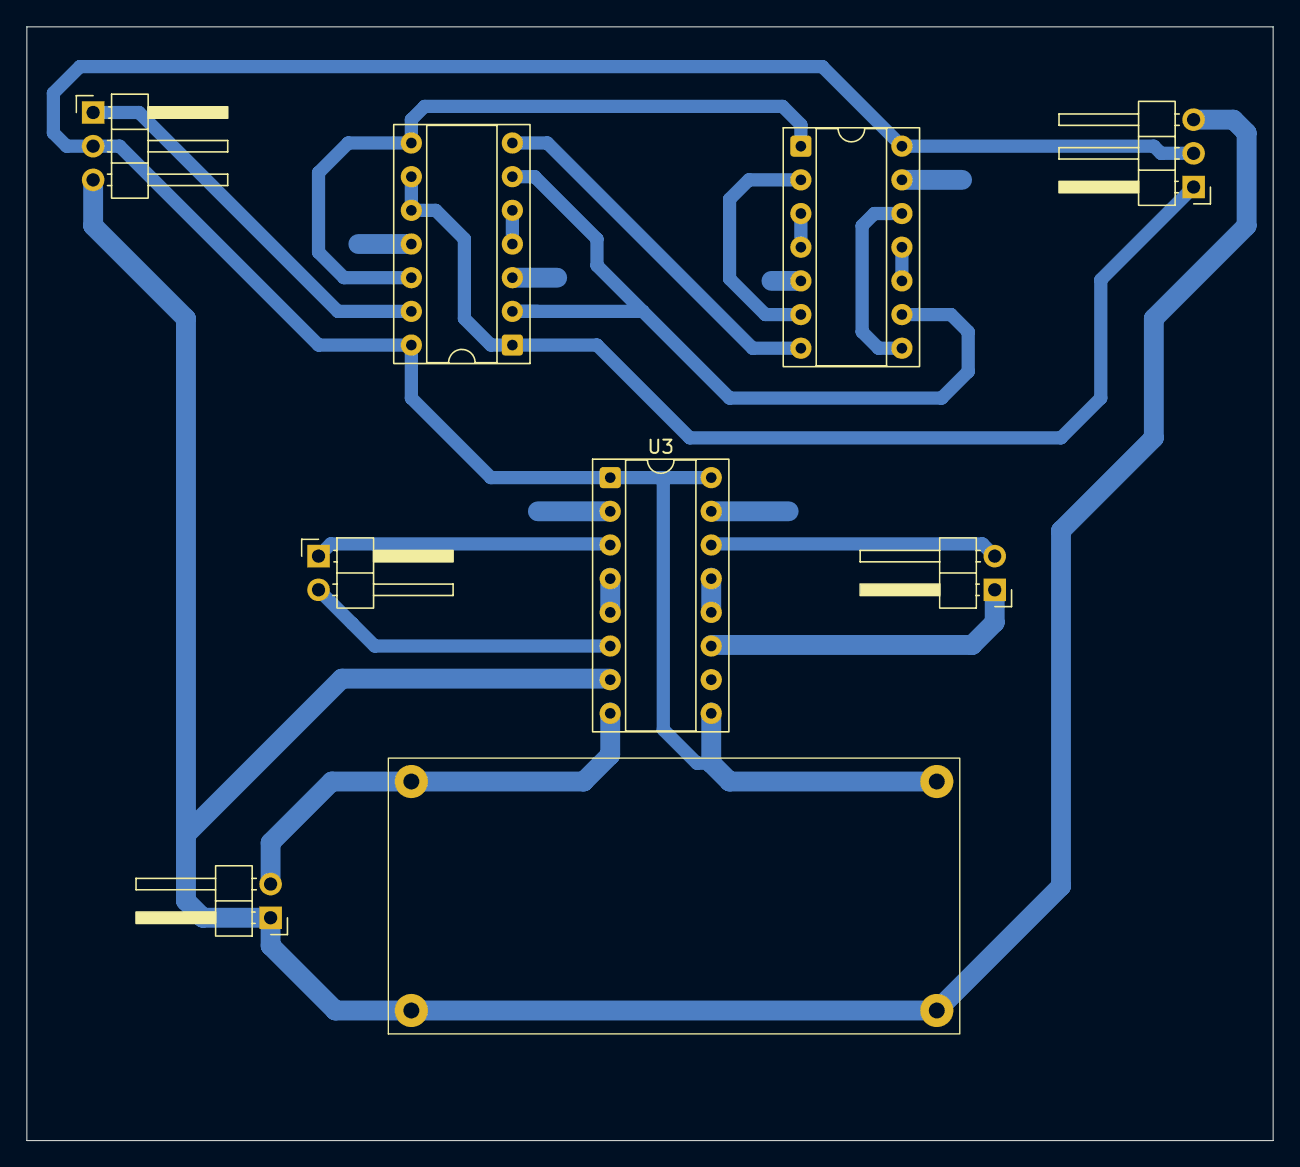
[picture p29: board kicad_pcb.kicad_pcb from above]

Board: 2 copper layers, 94.0 x 84.0 mm, 9 parts (0 on the bottom side), 17 nets.
